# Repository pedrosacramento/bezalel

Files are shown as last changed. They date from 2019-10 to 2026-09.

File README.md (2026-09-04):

# Bezalel — Open-source, 3D-printable, low-cost tactile display
banner

**Bezalel** is an open-source technology for building **tactile interfaces** using **3D printing** and **a minimal number of actuators**.  
It enables makers, researchers, and educators to prototype **shape-changing displays** that are affordable and easy to build.

## 🚀 Key Features
- **Low-cost & efficient:** Control many pins with few actuators  
- **Fully open-source:** All mechanical designs are 3D printable  
- **Modular & educational:** Ideal for research, accessibility, and learning projects

## 🧩 How it works
Bezalel introduces a **novel actuation principle** where a small set of actuators controls an entire grid of pins.

Two orthogonal groups of actuators push or pull an array of rotary elements, efficiently converting their motion into independent pin actuation.

This enables:
- High refresh speed  
- Minimal actuator count (scales linearly, not quadratically)  
- FDM friendly 3D printable mechanical assemblies

👉 Learn more in this [YouTube explanation](https://www.youtube.com/watch?v=fyhcJz_-Ox4).

animation

## 🧠 The 3D-printable prototype
We provide a **3×3 matrix prototype** implementing the Bezalel principle.

This model demonstrates how a low number of actuators can control a tactile pin array.

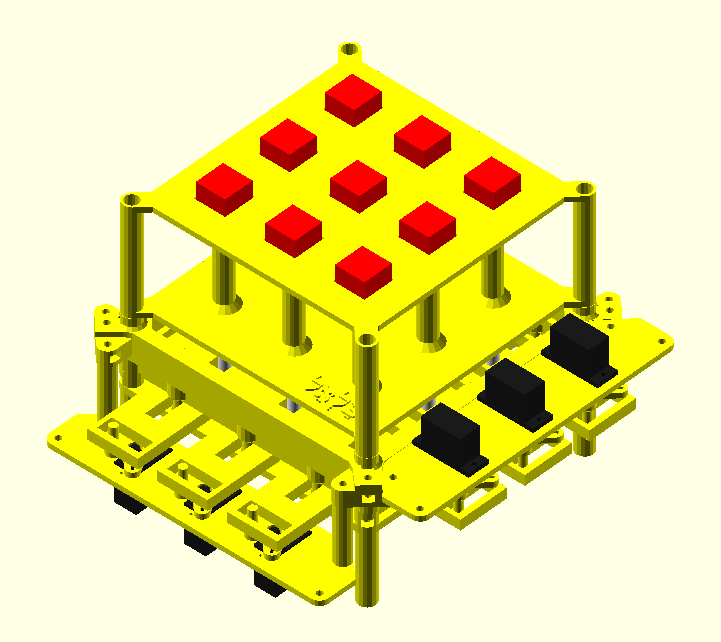
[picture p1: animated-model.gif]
Animated 3x3 model


- Controlled via **GRBL 1.1h firmware**  
- [Latest iteration video](https://www.youtube.com/shorts/zZdskc9G0Oo)

## 💡 Why tactile displays matter
Tactile interaction is a key frontier in **human-computer interaction**, particularly for **assistive technologies** for the blind and visually impaired.

Traditional tactile displays are expensive because each pin usually needs its own actuator — making cost grow **quadratically** with resolution.

Bezalel breaks this limitation, offering a **low-cost, maker-friendly** alternative.

📘 See the [EU Horizon Tactile Display Prize](https://digital-strategy.ec.europa.eu/en/news/european-commission-announces-eu3-million-horizon-prize-develop-tactile-display-visually-impaired) for context on the importance of such technologies.

## 🛠️ Roadmap

### 2026
- ⏲️ Started exploring Bezalel for **human-AI interaction**

### 2025
- ⏲️ Started an **inclusive tactile educational game**, using Bezalel technology, for both blind and sighted children (📹 [Video (in progress)](https://www.youtube.com/shorts/zZdskc9G0Oo) | 🎮 [Web Simulator](https://pedrosacramento.github.io/tictactoe/))

### Past milestones
#### 2024
- 🥈 Runner-up — *Visual Impairments* category, [Build2gether 2.0 (Hackster.io / ETH Zurich)](https://www.hackster.io/pedrosacramento/bezalel-open-source-3d-printable-tactile-display-5aa8e6) (📹 [Video](https://www.youtube.com/shorts/BmYJGurla8U))
#### 2023
- 🏅 Featured among [Top 100 Create The Future Design Contest submissions](https://contest.techbriefs.com/2023/top-100) (📹 [Video](https://www.youtube.com/watch?v=p8M2p39o1eg))
#### 2022
- 🧱 Published the **first 3D-printable 3×3 proof of concept** (📹 [Video (only pins)](https://www.youtube.com/watch?v=CwHi78mkTRg))

## 🌍 Long-term vision
We expect this technology to serve as the foundation for a new generation of 3D-printable interfaces that do not rely on vision or hearing.  

Among the products we envision are educational devices for teaching programming and music, as well as tactile games.

## ❤️ Motivation
When my wife was pregnant with our second child, she was misdiagnosed with an infection that could cause blindness in our daughter.

Thankfully, it was a false alarm - but it deeply moved me to revisit an old idea: building **tactile interfaces** to empower blind individuals.

This project reflects a personal pursuit that bridges faith and craftsmanship. It is named Bezalel, after the biblical figure who expressed his technical and artistic skills as a form of worship to God.

## ⚖️ Legal notice

### License
- **STL files**: Creative Commons Attribution 4.0 International (CC BY 4.0)
- **Code**: Apache 2.0

© Pedro Sacramento

### Patent
Bezalel's mechanical design is covered by Brazilian patent BR 102019021008 (filed 2019, granted May 2026).

Open-source hardware and patent rights can coexist. The STL files and code remain freely available under their respective licenses, but the patent governs how the mechanism may be used in Brazil:

- **Research and personal use** — free
- **Commercial use in Brazil** — requires a license

For commercial licensing inquiries, contact Pedro Sacramento.

## 🤝 How to contribute

### Build • Share • Adapt
You’re encouraged to 3D print, modify, and expand Bezalel for your own projects.  
Please share your results so others can learn from them too.

### Cite our work
If you use Bezalel in academic research, please cite our SIGGRAPH Asia paper:
```
Pedro de Almeida Sacramento, Ricardo dos Santos Ferreira, and Marcus Vinicius Alvim Andrade. 2019. Bezalel - Towards low-cost pin-based shape displays. In SIGGRAPH Asia 2019 Technical Briefs (SA ’19 Technical Briefs), November 17–20, 2019, Brisbane, QLD, Australia. ACM, New York, NY, USA, Article 4, 4 pages. https://doi.org/10.1145/3355088.3365144
```

## 🔗 Links
- [YouTube: Mechanism overview](https://www.youtube.com/watch?v=fyhcJz_-Ox4)  
- [Hackster.io project page](https://www.hackster.io/pedrosacramento/bezalel-open-source-3d-printable-tactile-display-5aa8e6)  
- [SIGGRAPH Asia 2019 Paper](https://doi.org/10.1145/3355088.3365144)

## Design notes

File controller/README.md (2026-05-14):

# controller

Host-side scripts and configuration for driving Bezalel hardware via vanilla g-code firmwares (GRBL and similar). Includes Python scripts that send g-code and GRBL `$$` runtime profiles.

Contents to be added.

## License

Code in this directory is licensed under the Apache License 2.0. See [LICENSE](LICENSE).

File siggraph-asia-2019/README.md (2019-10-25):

# Bezalel Simulator (HTML5)

## Author
Pedro de Almeida Sacramento

## Summary
This repository has the source code of the pin-based shape display simulator and the test files mentioned in the SIGGRAPH ASIA 2019 Technical Brief "Bezalel - Towards low-cost pin-based shape displays"

## License
GNU Affero General Public License v3.0

## Test
You can test Bezalel Simulator [here](https://pedrosacramento.github.io/bezalel/index.html)

## Abstract
The usage of shape changing interfaces is widely discussed in the HCI field as a promising strategy for the physical representation of digital data. Such interfaces are expected to greatly impact a wide range of applications, such as virtual reality, architectural design and education of blind people. Unfortunately, the widespread usage of pin-based shape displays is currently limited by their typically high manufacturing costs. The high costs of pin-based shape displays are mainly due to the number of actuators, which tends to grow quadratically with display resolution. Given that, we present Bezalel: a solution for pin-based shape displays that allows 2√n actuators to efficiently actuate pin-based shape displays with n pins. Our solution is able to fully render any 2.5D shape within a time proportional to √n, which outperforms the 2014 Lemelson-MIT "Use it!" graduate winner solution using half as much actuators. Additionally, results also show that, for specific shapes, our approach can perform as well as the most efficient and much more expensive technologies currently used. We expect that our solution will make it possible to create low-cost actuated surfaces with different sizes, from small tactile objects to large structures such as shape-changing floors.

## Authors
* Pedro de Almeida Sacramento [LinkedIn](https://br.linkedin.com/in/pedro-sacramento-1b99b05b)
* Ricardo dos Santos Ferreira [LinkedIn](https://www.linkedin.com/in/ricardo-ferreira-188b9316/)
* Marcus Vinicius Alvim Andrade [University](http://www2.dpi.ufv.br/?page_id=542)

## When using Bezalel please reference:
Pedro de Almeida Sacramento, Ricardo dos Santos Ferreira, and Marcus Vinicius Alvim Andrade. 2019. Bezalel - Towards low-cost pin-based shape displays. In SIGGRAPH Asia 2019 Technical Briefs (SA ’19 Technical Briefs), November 17–20, 2019, Brisbane, QLD, Australia. ACM, New York, NY, USA, Article 4, 4 pages. https://doi.org/10.1145/3355088.3365144

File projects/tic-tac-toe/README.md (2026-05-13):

# Tic-Tac-Toe

A tactile, screen-free interface built on the Bezalel actuation principle, playable by blind and sighted children together and able to interact with an AI agent through touch and physical moves instead of a display.

- 🎮 [Web simulator](https://pedrosacramento.github.io/tictactoe/)
- 📹 [Video (work in progress)](https://www.youtube.com/shorts/S2y2Thsf4AI)

The `stl/` folder contains the 3D-printable parts for the current prototype.

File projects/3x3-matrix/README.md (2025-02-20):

# Bezalel

This folder contains the mechanical model of the Bezael device that has been designed for being actuated using stepper motors video ([video1](https://youtube.com/shorts/rH5o1_4vkyY), [video2](https://youtube.com/shorts/BmYJGurla8U))

## Hardware
* 2 x Nema 17 7.3kgf.cm stepper motor ([example](https://pt.aliexpress.com/item/4000199292267.html))
* 1 x Arduino Uno R3 [example](https://www.amazon.com/Arduino-A000066-ARDUINO-UNO-R3/dp/B008GRTSV6))
* 1 x CNC Shield V3 ([example](https://www.amazon.com/HiLetgo%C2%AE-Engraver-Printer-Expansion-Arduino/dp/B01D2HL9T8))
* 2 x A4988 drivers ([example](https://www.amazon.com/HUAREW-Stepstick-Arduino-Printer-Robotics/dp/B0CS3LJYKG))
* 1 x 12V 3A power adapter ([example](https://www.amazon.com/Mounted-100-240V-Switching-Transformer-Connector/dp/B087NPBC1W?th=1))
* 21 x 3x100mm shaft ([example](https://aliexpress.com/item/32967805012.html)
* 21 x 3.1mm shaft collar ([example](https://pt.aliexpress.com/item/1005003321096391.html))

## Softwares
* Universal G-code Sender (https://winder.github.io/ugs_website/)
* Grbl v1.1 (https://github.com/gnea/grbl)

## How to assemble
A video will be uploaded soon. Please refer to [this Hackster.io entry](https://www.hackster.io/pedrosacramento/bezalel-open-source-3d-printable-tactile-display-5aa8e6) for more details until the new video is uploaded

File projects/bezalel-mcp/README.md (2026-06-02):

# bezalel-mcp

MCP server for the Bezalel project, providing tools to control an Arduino-connected display via the [Model Context Protocol](https://modelcontextprotocol.io).

## Configuration

The bridge server URL is set via the `BEZALEL_BRIDGE_URL` environment variable. If not set, it defaults to `http://localhost:8080`.

In `.mcp.json`, pass the env var like this:

```json
{
  "mcpServers": {
    "bezalel-mcp": {
      "command": "node",
      "args": ["projects/bezalel-mcp/dist/index.js"],
      "env": {
        "BEZALEL_BRIDGE_URL": "http://192.168.1.100:8080"
      }
    }
  }
}
```

## Prerequisites

A bridge HTTP server must be running at the configured URL that accepts POST requests to the `/move` endpoint with a cell reference (e.g. `a1`, `B2`, `c3`) as the plain-text body. This server bridges MCP tool calls to the Arduino display hardware.

## Tools

- **update_cell** — Updates a cell on the Arduino-connected display. Accepts a `cell` parameter with a cell reference like `A3`, `b2`, `c1`.

## Install

```bash
cd projects/bezalel-mcp
npm install
npm run build
```

## Usage with Claude Code

Add a `.mcp.json` at the repo root (already done for this project):

```json
{
  "mcpServers": {
    "bezalel-mcp": {
      "command": "node",
      "args": ["projects/bezalel-mcp/dist/index.js"],
      "env": {
        "BEZALEL_BRIDGE_URL": "http://localhost:8080"
      }
    }
  }
}
```

On next launch, Claude Code will prompt to approve the new server. Once approved, the `update_cell` tool is available directly in the session.

### In-session usage

Once the MCP server is connected, ask Claude to update a cell:

```
> update a2
```

Claude will invoke the `update_cell` tool, which sends the cell reference to the bridge server and reports the result.

## Run standalone

The server communicates over stdio and can be connected to any MCP client:

```bash
npm start
```

## License

Code in this directory is licensed under the Apache License 2.0.

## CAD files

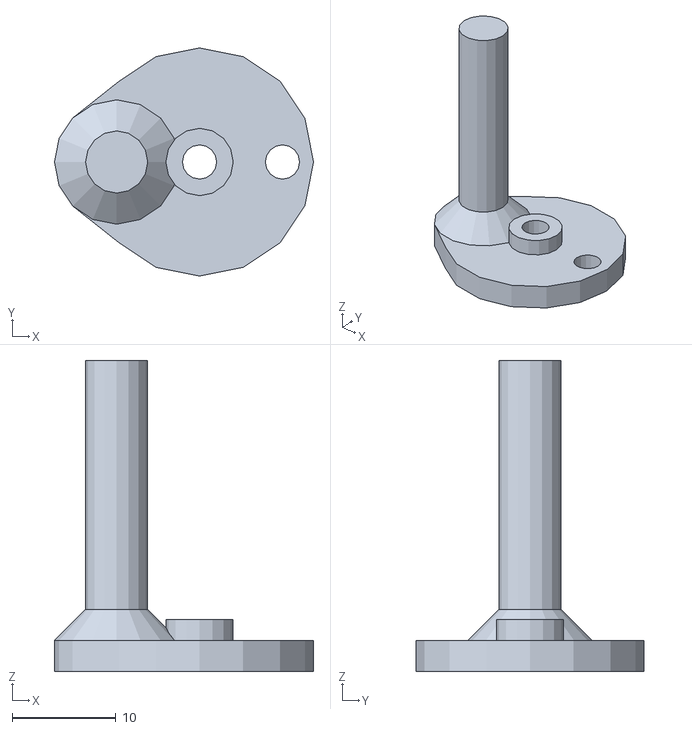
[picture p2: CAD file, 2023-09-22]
3d-printable-device-september-2023/parts/3dprint/crank.stl
25.0 x 22.0 x 30.0

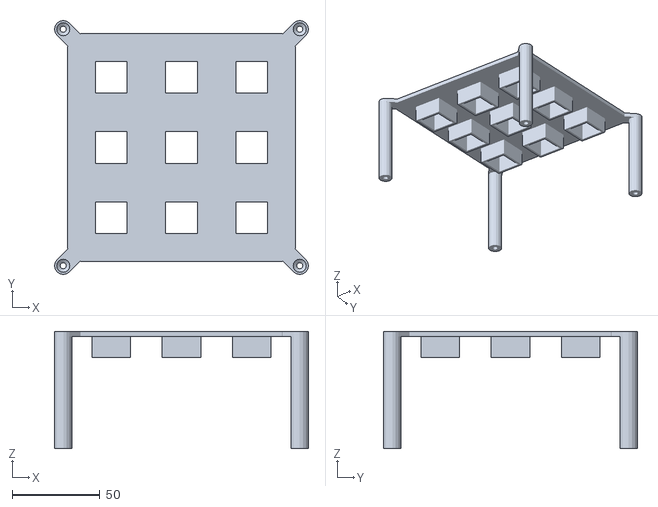
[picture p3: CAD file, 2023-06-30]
create-the-future-design-contest-2023/part-004.stl
145.0 x 145.0 x 67.0

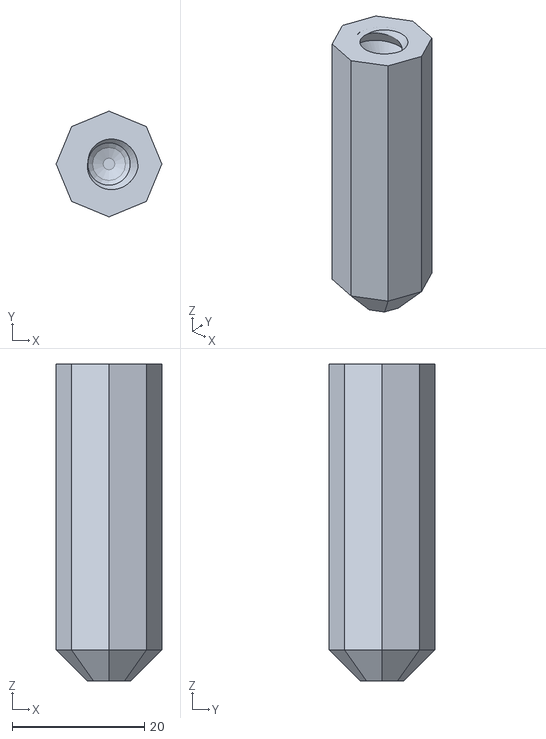
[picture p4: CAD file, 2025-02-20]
projects/3x3-matrix/stl/008_v1.stl
16.0 x 16.0 x 48.0

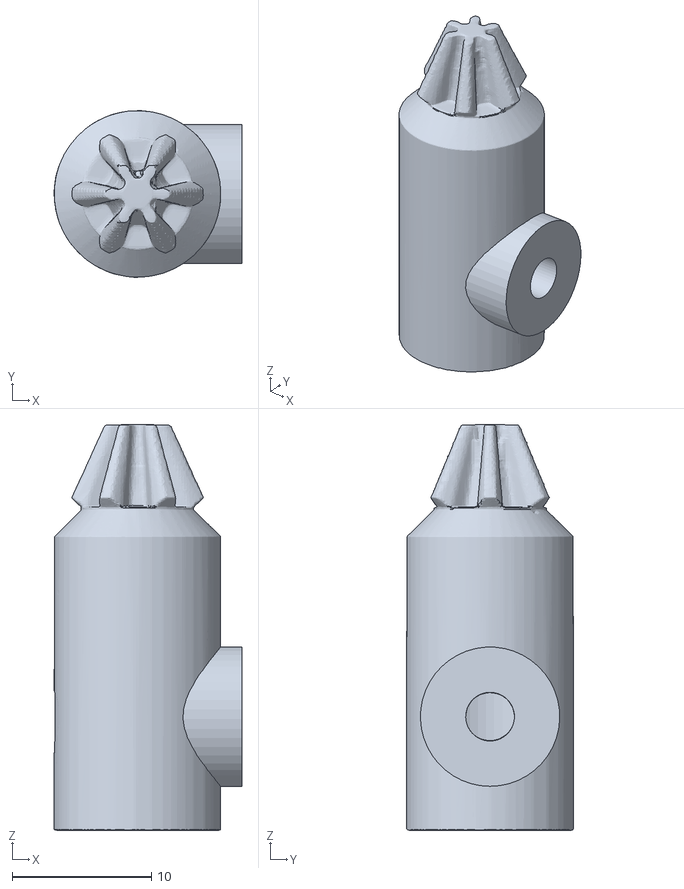
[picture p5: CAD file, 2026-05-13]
projects/tic-tac-toe/stl/digit_control_gear.stl
13.5 x 12.0 x 29.1

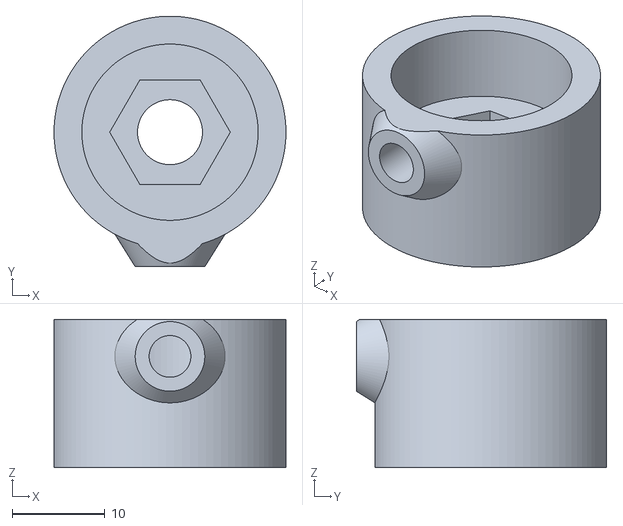
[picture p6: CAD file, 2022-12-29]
3d-printable-device-2022/3x3-device_functional/part-005-coupling-adapter.stl
25.0 x 27.0 x 16.0

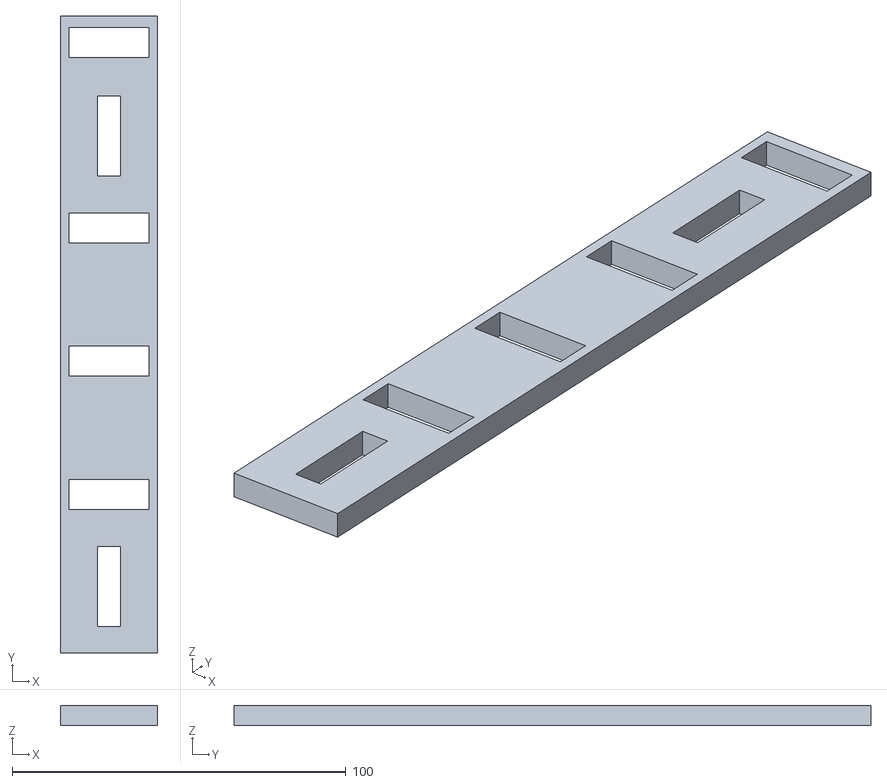
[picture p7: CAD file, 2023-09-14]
3d-printable-device-september-2023/parts/3dprint/slider.stl
29.0 x 191.0 x 6.00

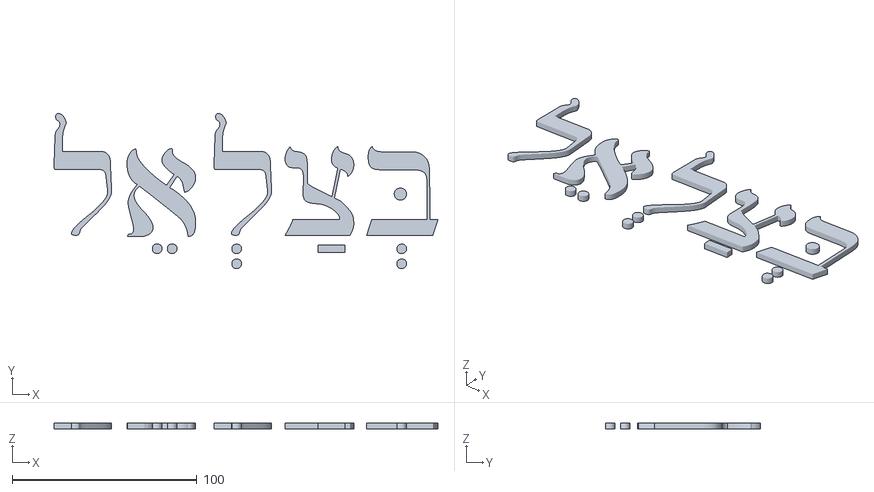
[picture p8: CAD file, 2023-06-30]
create-the-future-design-contest-2023/bezalel.stl
207.8 x 83.9 x 3.00

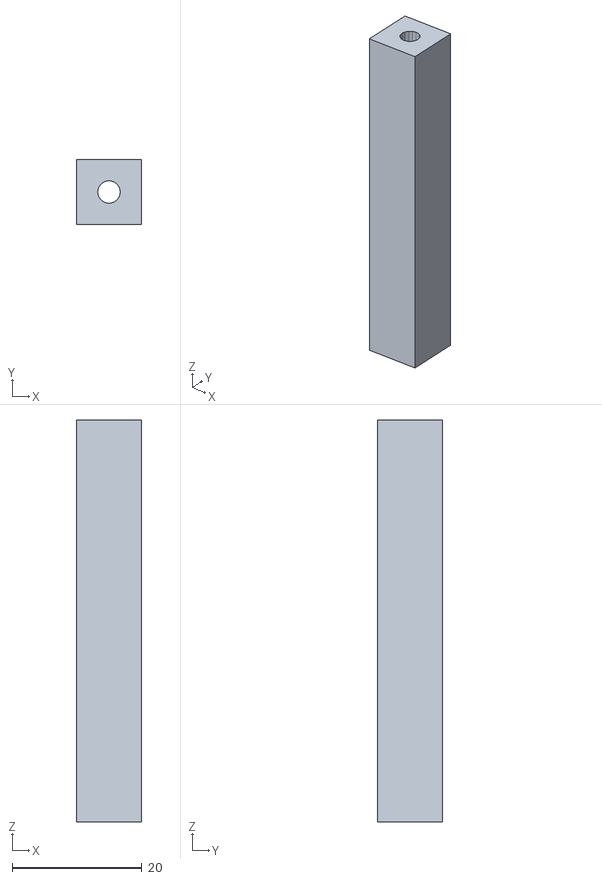
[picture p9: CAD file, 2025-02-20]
projects/3x3-matrix/stl/001_v1.stl
10.0 x 10.0 x 62.0

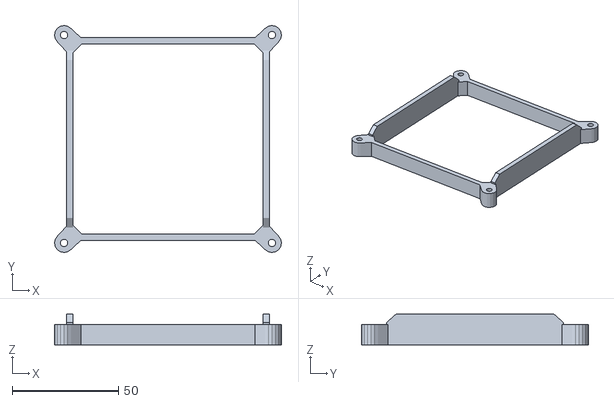
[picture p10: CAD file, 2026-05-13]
projects/tic-tac-toe/stl/slider_bottom_lock.stl
107.0 x 107.0 x 14.5

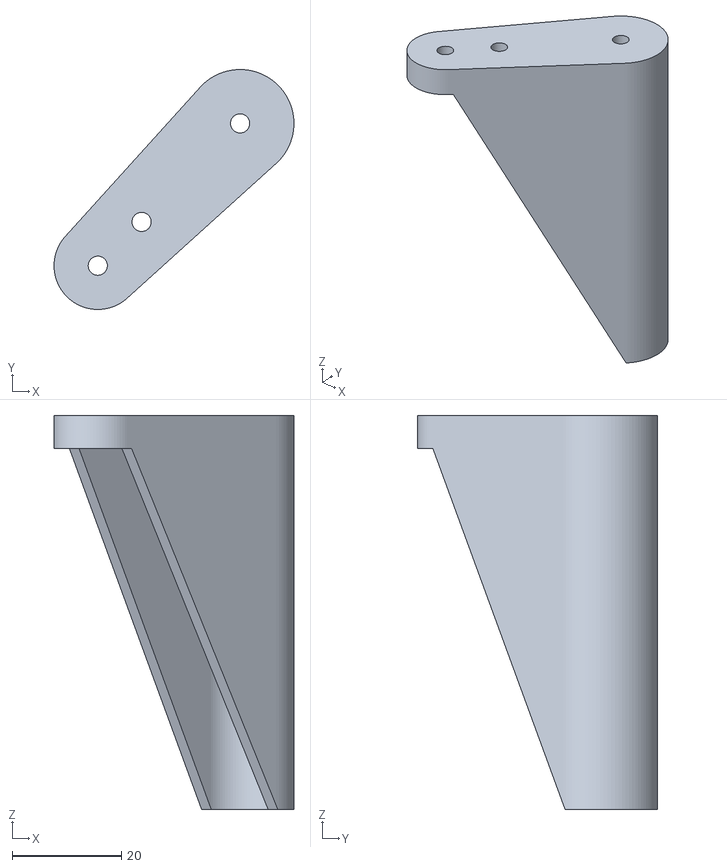
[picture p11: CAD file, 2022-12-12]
3d-printable-device-2022/3x3-device_functional/part-003.stl
43.8 x 43.8 x 72.0

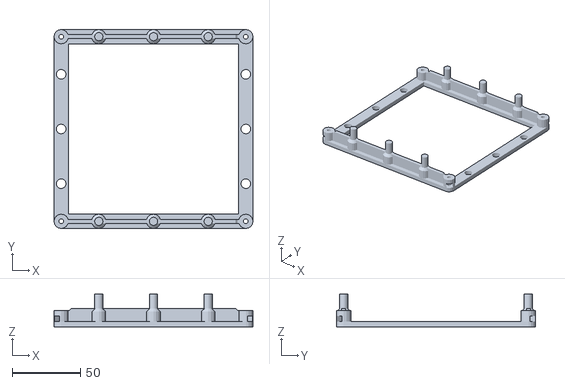
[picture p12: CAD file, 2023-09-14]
3d-printable-device-september-2023/parts/3dprint/slider-rails-bottom.stl
145.5 x 145.5 x 24.0

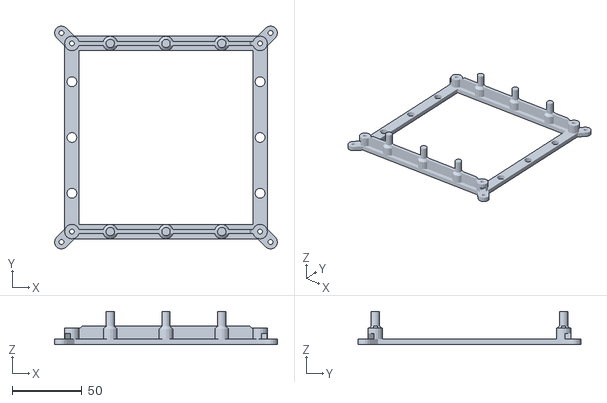
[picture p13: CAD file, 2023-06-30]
create-the-future-design-contest-2023/part-005-bottom.stl
160.0 x 160.0 x 24.0

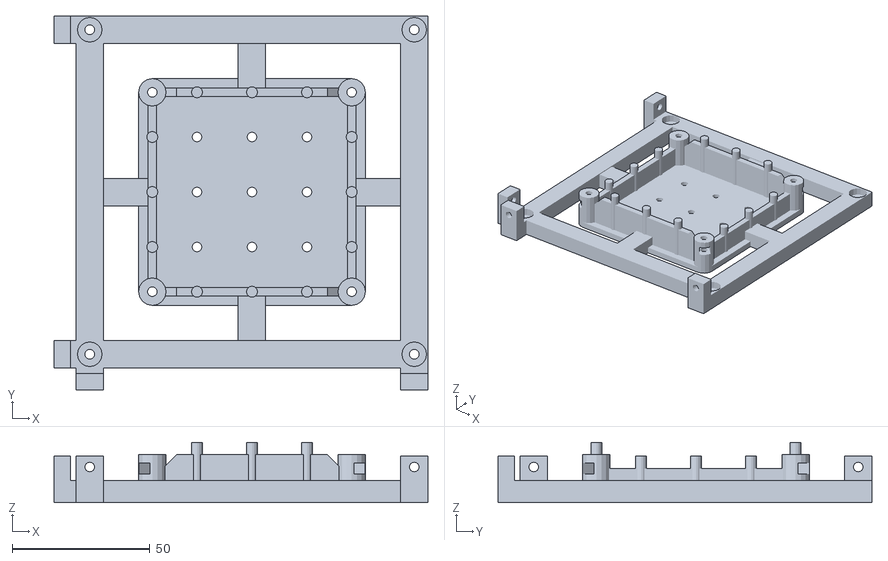
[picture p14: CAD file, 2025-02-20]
projects/3x3-matrix/stl/010_v6_bottom.stl
136.0 x 136.0 x 22.0

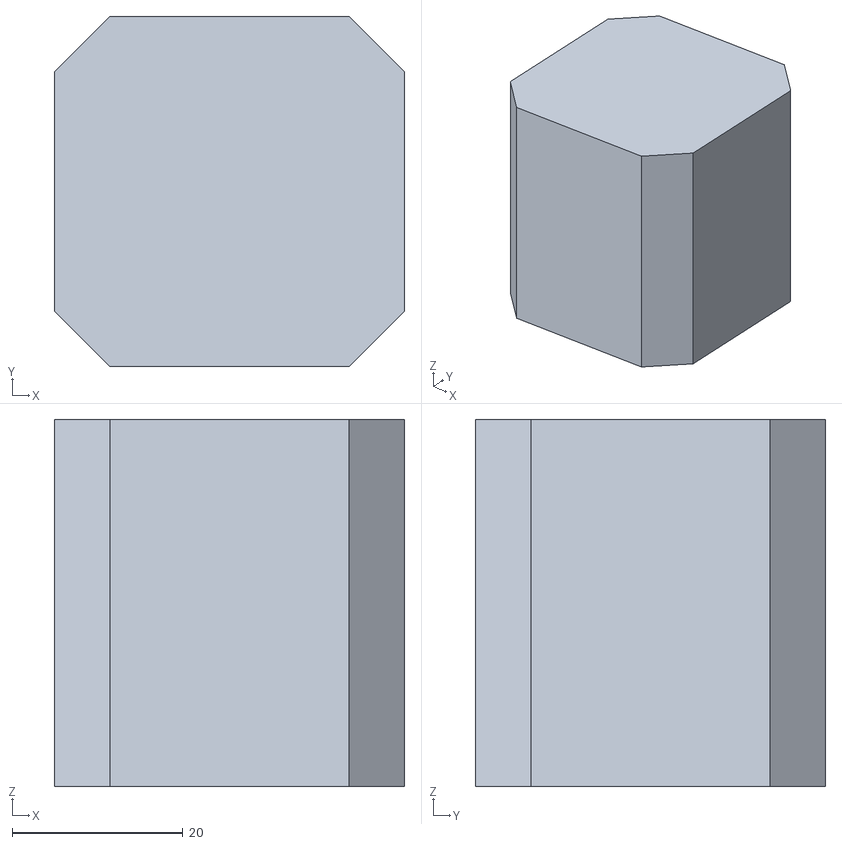
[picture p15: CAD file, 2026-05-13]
projects/tic-tac-toe/stl/motor_black.stl
41.0 x 41.0 x 43.0

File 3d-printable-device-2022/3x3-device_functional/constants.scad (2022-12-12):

HOME_ANGLE = 45; // degrees
HOME_ANIM_RANGE = 90; // degrees
DEFAULT_ANIM_RANGE = 360; // degrees
COLUMN_REFRESH_STEPS=(HOME_ANIM_RANGE+DEFAULT_ANIM_RANGE+HOME_ANIM_RANGE)/HOME_ANIM_RANGE;
CRANK_ARM = 8; // in mm
SERVO_ARM = 16; // in mm
time = $t;

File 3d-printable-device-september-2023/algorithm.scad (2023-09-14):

HOME_ANGLE = 45; // degrees
HOME_ANIM_RANGE = 90; // degrees
DEFAULT_ANIM_RANGE = 360; // degrees
COLUMN_REFRESH_STEPS=(HOME_ANIM_RANGE+DEFAULT_ANIM_RANGE+HOME_ANIM_RANGE)/HOME_ANIM_RANGE;
CRANK_ARM = 8; // in mm
SERVO_ARM = 9; // in mm
time = $t;

function getGlobalTime() = (time * len(animation))%1;
function getLocalTime() =
    (getGlobalTime() - getHomingDuration()) / getStepDuration();
function getStepDuration() = ((COLUMN_REFRESH_STEPS - 2) / COLUMN_REFRESH_STEPS);

function getCurrentScene() = floor(time * len(animation));
function getSceneData(n) = animation[n];
function getCurrentSceneData() = getSceneData(getCurrentScene());
function getHomingDuration() = (1 / COLUMN_REFRESH_STEPS);

function isPartVisible(n) = len(search(n, visibleParts)) > 0;

function isHomingState() = isHomingBefore() || isHomingAfter();
function isHomingBefore() = getGlobalTime() < getHomingDuration();
function isHomingAfter() = getGlobalTime() > 1 - getHomingDuration();

function servoRowRotation(i) = servoRowAnimation(i);
function servoColRotation(j) = servoColAnimation(j);

function servoHomeAnimationBefore() = HOME_ANGLE + (getGlobalTime() / getHomingDuration()) * 90;
function servoHomeAnimationAfter() =
    (180 - HOME_ANGLE) - (getGlobalTime() - getHomingDuration())/getStepDuration() * 360;

function servoAnimation01() = (!isHomingState()) ?
    HOME_ANGLE + 360 * getLocalTime() :
    HOME_ANGLE;    
function servoAnimation02() =
    (isHomingBefore())?
        servoHomeAnimationBefore() :
    (isHomingAfter()) ?
        servoHomeAnimationAfter() :
    180 - servoAnimation01();
function servoAnimation03() = servoAnimation01();

function servoAnimation04() =
    (!isHomingState()) ?
    360 - servoAnimation01()
    :
    180 + HOME_ANGLE;
    
function servoRowAnimation(i) = (
    getRowServoState(i) == 1 ? servoAnimation01() :
    getRowServoState(i) == 2 ? servoAnimation02() : 
45);
function servoColAnimation(j) =
    (getColServoState(j) == 1) ?
        servoAnimation03() :
    HOME_ANGLE;

function servoRowTranslation(i) = cos(servoRowRotation(i)) * CRANK_ARM;
function servoColTranslation(j) = sin(servoColRotation(j)) * CRANK_ARM;

function servoColAdjustedRotation(j) = -asin(servoColTranslation(j) / SERVO_ARM) + 90;
function servoRowAdjustedRotation(i) = acos(servoRowTranslation(i) / SERVO_ARM);

function getRowServoState(i) = getCurrentSceneData()[0][i];
function getColServoState(j) = getCurrentSceneData()[1][j];

function getPinHeightOffset(i,j,n) =
    getSceneData(n)[1][j] == 1 && getSceneData(n)[0][i] ==  1 ?  1 :
    getSceneData(n)[1][j] == 1 && getSceneData(n)[0][i] ==  2 ? -1 :
    0;
function getPinHeightStart(i,j,n) = n > 0 ? getPinHeightEnd(i,j,n-1) : 0;
function getPinHeightEnd(i,j,n) = getPinHeightStart(i,j,n) +
    getPinHeightOffset(i,j,n);
function getPinHeightInterpolation(i,j,n) = getPinHeightStart(i,j,n) + getPinHeightOffset(i,j,getCurrentScene()) * getLocalTime();
function getPinHeight(i,j) = 
    isHomingBefore() ? getPinHeightStart(i,j,getCurrentScene()) :
    isHomingAfter() ? getPinHeightEnd(i,j,getCurrentScene()) :
    getPinHeightInterpolation(i,j,getCurrentScene());
function getCrankRotation(i,j) = 180 + (atan2(sin(servoColRotation(j)),cos(servoRowRotation(i))));

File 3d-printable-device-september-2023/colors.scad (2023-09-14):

color_white = [1,1,1];
color_black = [0.1,0.1,0.1];
color_gray = [0.5,0.5,0.5];
color_red = [1,0,0];
color_blue = [0,0,1];
color_yellow = [1,1,0];
color_orange = [1,0.5,0];

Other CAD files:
3d-printable-device-2022/3x3-device_functional/MG995.stl
3d-printable-device-september-2023/parts/3dprint/bezalel.stl
create-the-future-design-contest-2023/part-005-top.stl
projects/3x3-matrix/stl/000_v25_low.stl
3d-printable-device-september-2023/main.scad
3d-printable-device-2022/3x3-device_functional/algorithm.scad
3d-printable-device-2022/3x3-device_functional/model.scad
3d-printable-device-2022/3x3-device_functional/part-000-long-nut.stl
3d-printable-device-2022/3x3-device_functional/part-000.scad
3d-printable-device-2022/3x3-device_functional/part-000.stl
3d-printable-device-2022/3x3-device_functional/part-001.scad
3d-printable-device-2022/3x3-device_functional/part-001.stl
3d-printable-device-2022/3x3-device_functional/part-002.scad
3d-printable-device-2022/3x3-device_functional/part-002.stl
3d-printable-device-2022/3x3-device_functional/part-003.scad
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

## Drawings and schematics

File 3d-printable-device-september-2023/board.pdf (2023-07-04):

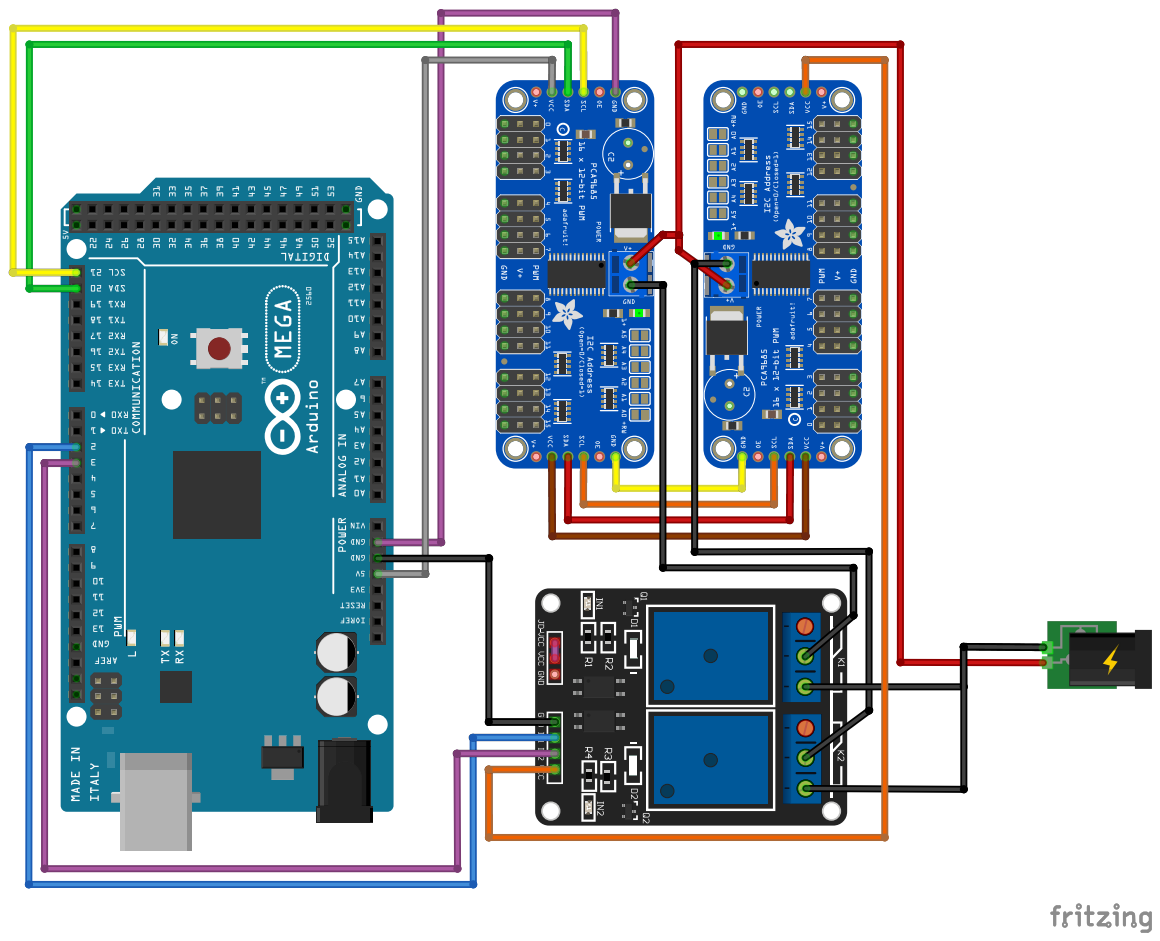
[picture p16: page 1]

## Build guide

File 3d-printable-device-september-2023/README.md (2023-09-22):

# Bezalel - An open-source 3D printable low-cost tactile display

This folder contains the OpenSCAD and STL files necessary to build a 3x3 matrix of vertical pins.
The STL files corresponds to the mechanical design of a 3x3 matrix, which demands only 6 servos.

## Version
2023.09

## 3D printable parts
For sake of reference, the table below provides additional details about 3D printed parts.

### Reference 3D printer settings
- **Ender 3:** An Ender 3 3D printer have been used as reference
- **No supports:** All the 3d printable parts have been designed to be printed without supports.
- **Gyroid infill:** All the tests have been performed with gyroid infill
- **Layer height:** 0.2mm

| Item  | Infill (%) | Amount | Description | Print time (HH:MM) | Link |
| --- | --- | --- | --- | --- | --- |
| Main | 20  | 1 | The first part to be 3D printed | 06:05 | [Link](parts/3dprint/main.stl) |
| Columns for cover structure | 20  | 4 | Columns that attach a cover structure to the main structure | 01:23 | [Link](parts/3dprint/column.stl) |
| Crank | 50  | 9 | Cranks that promote the lead screw rotation. This 3D printed part must be associated to the metal flange coupling connector and the metal rod | 00:27 | [Link](parts/3dprint/crank.stl) |
| Foot | 20  | 4 | Feet that support the whole device structure | 00:39 | [Link](parts/3dprint/foot.stl) |
| Lead screw | 50  | 9 | Lead screw that actuates the vertical pins. To ensure that it moves smoothly inside the pins, a 0.12 layer height is recommended. Lubrication is not necessary | 01:02 | [Link](parts/3dprint/lead-screw.stl) |
| Vertical pin | 20  | 9 | Vertical pins | 02:23 | [Link](parts/3dprint/pin.stl) |
| Servo arm | 50  | 6 | Servo arm | 00:11 | [Link](parts/3dprint/servo-arm.stl) |
| Servo support plate | 20  | 2 | Plate in which servos are attached | 01:41 | [Link](parts/3dprint/servo-support.stl) |
| Slider | 20  | 6 | Sliding structure that promotes crank rotation | 02:16 | [Link](parts/3dprint/slider.stl) |
| Slider rails (top) | 20  | 1 | Structure that attaches rails to the main structure | 04:29 | [Link](parts/3dprint/slider-rails-top.stl) |
| Slider rails (bottom) | 20  | 1 | Structure in which slider structures will slide | 04:16 | [Link](parts/3dprint/slider-rails-bottom.stl) |
| Spacer | 20  | 2 | Spacer that separates servo support plates and the main structure | 00:30 | [Link](parts/3dprint/spacer.stl) |
| Support for pins | 20  | 1 | Main support structure with bushings for pins metal rods | 11:53 | [Link](parts/3dprint/support-for-pins.stl) |
| Cover structure for pins | 20  | 1 | Device cover structure | 05:53 | [Link](parts/3dprint/top-plate.stl) |

## Materials
| Item  | US$ | Amount | Total | Link |
| --- | --- | --- | --- | --- |
| PCA9685  | 13.99  | 1 | 13.99 | [Link](https://www.amazon.com/HiLetgo-PCA9685-Channel-12-Bit-Arduino/dp/B07BRS249H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) |
| Arduino Mega  | 38.72  | 1 | 38.72 | [Link](https://store-usa.arduino.cc/collections/boards/products/arduino-mega-2560-rev3) |
| MG 90S  | 8.49  | 6 | 50.94 | [Link](https://www.amazon.com/Replace-Helicopter-Airplane-Controls-Vehicle/dp/B09KXM5L7Z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) |
| 1kg PLA  | 18.99  | 1 | 18.99 | [Link](https://www.amazon.com/Printer-Filament-SUNLU-Dimensional-Accuracy/dp/B07XG3RM58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) |
| M3 nuts, bolts, washers pack | 10.99  | 1 | 10.99 | [Link](https://www.amazon.com/Assortment-Stainless-Washers-Assorted-Machine/dp/B0BC24J6SS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) |
| Jumpers Pack | 6.98  | 1 | 6.98 | [Link](https://www.amazon.com/Elegoo-EL-CP-004-Multicolored-Breadboard-arduino/dp/B01EV70C78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) |
| M3 locknuts (pack contains 100 items) | 6.99  | 1 | 6.99 | [Link](https://www.amazon.com/100Pcs-Stainless-Self-Lock-Inserted-Clinching/dp/B075ZZW7VL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) |
| M3 shaft collar (pack contains 15 items) | 7.99  | 1 | 7.99 | [Link](https://www.amazon.com/Hobbypark-Landing-Stopper-Airplane-Replacement/dp/B01EA912P8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) |
| 3mm Flange Coupling Connector (pack contains 4 items) | 8.99  | 3 | 26.97 | [Link](https://www.amazon.com/Coupling-Connector-Coupler-Accessory-Fittings/dp/B083352VJH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) |
| 100mm x 3mm Metal shaft (pack contains 5 items) | 1.05 | 2 | 2.1 | [Link](https://www.aliexpress.com/item/32967805012.html) |

## Circuit
We've been making tests with the circuit available [here](board.pdf).
It has been designed to support up to 32 servos because we're planning to build matrices with more pins.

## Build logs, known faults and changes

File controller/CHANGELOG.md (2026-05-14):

# Changelog

All notable changes to this project will be documented in this file.

The format is based on [Keep a Changelog](https://keepachangelog.com/en/1.0.0/).

## [Unreleased]

## [0.2.0] - 2026-05-13

### Added
- Initial scaffolding and release automation

## [0.1.0-alpha.1] - 2026-05-13

### Added
- Initial scaffolding for host-side control scripts

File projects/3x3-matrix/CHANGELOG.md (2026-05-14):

# Changelog

All notable changes to this project will be documented in this file.

The format is based on [Keep a Changelog](https://keepachangelog.com/en/1.0.0/).

## [Unreleased]

## [0.2.0] - 2026-05-13

### Changed
- Reorganized repository structure

## [0.1.0-alpha.1] - 2026-05-13

### Added
- Initial release of 3×3 matrix design

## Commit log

2022-04-30 Adding 3D printable device
    3D printable model that implements the concept presented during SIGGRAPH asia 2019. The design is patent pending, but can freely used. The patent filing follows the defensive patent strategy used by 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
    [bezalel.scad, colors.scad, n000_square_grid.scad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]
2022-05-04 Delete n007_spacer.scad
    Removing file that was created by mistake
    [n007_spacer.scad]
2022-05-21 Update n006_horizontal_slider.scad
    Fixing vertical position of horizontal slider
    [n006_horizontal_slider.scad]
2022-05-21 Update and rename n005_vertical_block.scad to n005_vertical_pin.scad
    [n005_vertical_block.scad, n005_vertical_pin.scad]
2022-05-21 Changing STL to n005_vertical_pin.stl
    [n005_vertical_pin.stl]
2022-05-21 Delete n005_vertical_block.stl
    Removing old file "vertical_block"
    [n005_vertical_block.stl]
2022-05-21 Update bezalel.scad
    Changing "vertical_block" to "vertical_pin" to better describe device parts.
    [bezalel.scad]
2022-05-22 Changing "bushings" to "main_plane"
    [n001_main_plane.stl, n001_main_plane_acrylic.stl]
2022-12-12 Add 3x3 functional 3d printable model
    [MG995.stl, algorithm.scad, bezalel.scad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]
2022-12-28 Fix issue on pin animation
    [part-002.scad]
2022-12-29 Add simplified lead screw among other parts
    [model.scad, part-000-long-nut.stl, part-000.scad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]
2023-06-30 Delete 3d-printable-device-2022/8x8-device_wip directory
    Remove old directory
    [bezalel.scad, colors.scad, n000_square_grid.scad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]
2023-06-30 Publish algorithm and 3D printable STL files
    [algorithm.scad, animation.scad, bezalel.stl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]
2023-07-04 Add fritzing board.pdf
2023-09-14 September 2023 updated mechanical model
    [3mm-rod.stl, algorithm.scad, bezalel.stl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]
2023-09-22 Update lead screw and crank
    [crank.stl, lead-screw.stl]
2024-01-10 First iteration with G-CODE support
    [3mm-rod.stl, bezalel.stl, cam.stl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]
2024-01-13 Beginning major changes to folder structure
    [3mm-rod.stl, MG995.stl, algorithm.scad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]
2024-01-13 Remove older release files
    [3mm-rod.stl, MG995.stl, algorithm.scad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]
2025-02-20 Update latest STL files
    [000_v25.stl, 000_v25_low.stl, 001_v1.stl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]
2026-05-13 Restructure src/ into projects/3x3-matrix/ and add CC BY 4.0 license
    Move the 3D-printable design files (OpenSCAD source and STL exports)
    into projects/3x3-matrix/ to make room for additional project variants.
    Add a CC BY 4.0 license for the printable parts and update the root
    README to clarify the dual-licensing arrangement (GPLv3 for the
    overall project, CC BY 4.0 for the 3D-printable assets).
    [000_v25.stl, 000_v25_low.stl, 001_v1.stl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]
2026-05-13 Simplify license framing: code is GPLv3, STL files are CC BY 4.0
    Reword the root README license section into a two-line split and update
    the per-project LICENSE header to scope CC BY 4.0 to STL files only,
    deferring main.scad (OpenSCAD source) to the repository-root GPLv3.
2026-05-13 Update project files and add tic-tac-toe STL assets
    [actuator_mount_frame_external.stl, actuator_mount_frame_internal.stl, aluminium_rod.stl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]
2026-05-14 Add firmware/ placeholder for shared microcontroller resources
    Reserves a top-level home for Arduino, ESP32, and GRBL code shared
    across projects. Contents to follow.
2026-05-14 Rename firmware/ to controller/, add Apache 2.0 license
    The directory will hold host-side scripts (Python g-code senders) and
    GRBL runtime configuration rather than microcontroller firmware, so
    "controller" describes the contents more honestly.
    - Rename firmware/ -> controller/, rewrite the README accordingly.
    - Add Apache 2.0 LICENSE inside controller/.
    - Root README license section: drop the interim hedge; STL is CC BY 4.0,
    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
2026-05-14 Clarify patent status and remove future licensing commitments
    Simplify patent statement to:
    - State current unrestricted status clearly
    - Note patent is pending in Brazil only
    - Leave future licensing decisions open
    Removes language that would constrain a potential acquirer's options.
